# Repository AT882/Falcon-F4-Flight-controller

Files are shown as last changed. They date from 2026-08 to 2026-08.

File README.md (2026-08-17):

# Falcon F4 Flight Controller

Custom STM32F405-based flight controller designed for UAV, FPV and aerial robotics applications.

## Overview

The Falcon F4 Flight Controller is a custom-designed flight-control board based on the STM32F405RGT6 ARM Cortex-M4 microcontroller.

The board integrates the core hardware required for a compact UAV flight-control system, including a 6-axis IMU, barometric pressure sensor, analog video OSD, external SPI Flash memory, regulated power supplies, battery-voltage monitoring, current sensing, ESC interfaces, camera and VTX interfaces, USB connectivity and SWD debugging.

The complete electrical schematic is provided in this repository along with images of the designed PCB.

## Hardware Images

### PCB Front View

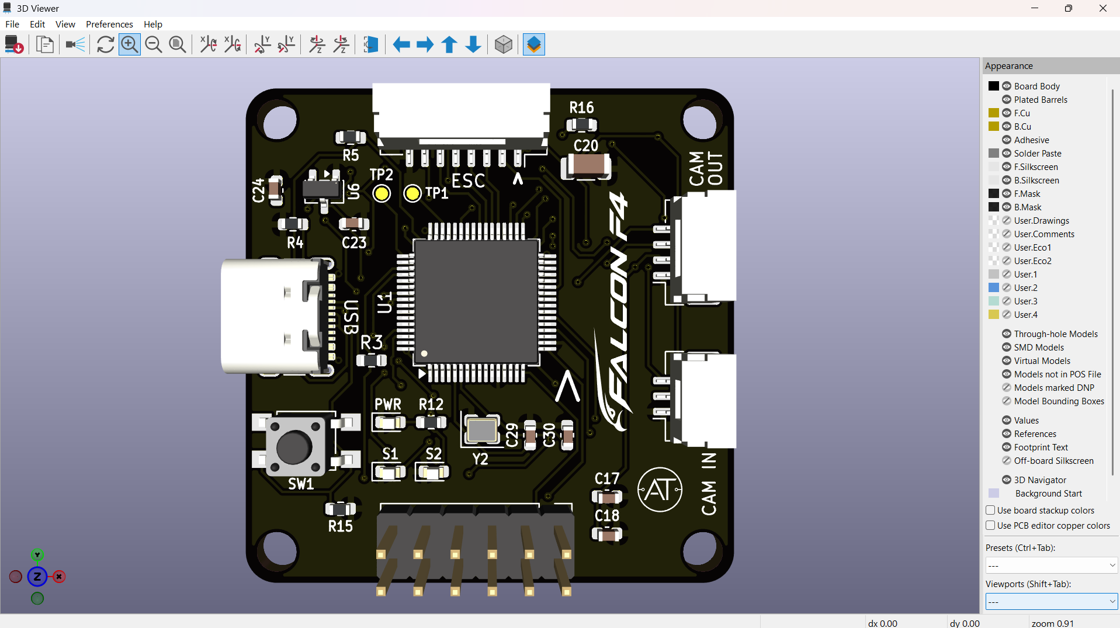
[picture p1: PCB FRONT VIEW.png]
Falcon F4 Flight Controller - Front View


### PCB Back View

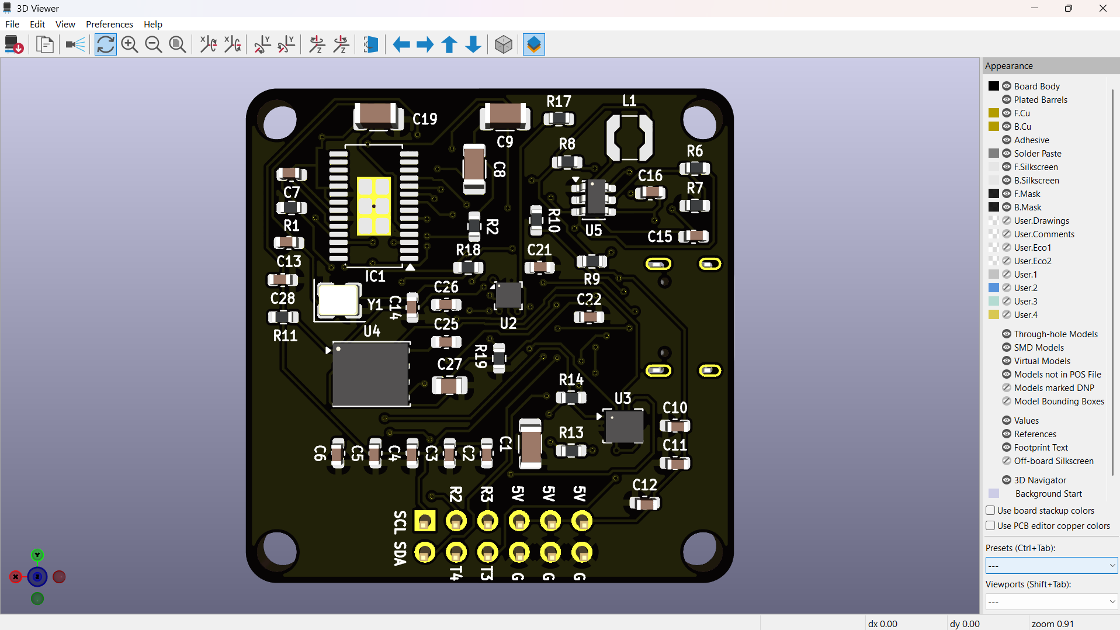
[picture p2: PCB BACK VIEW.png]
Falcon F4 Flight Controller - Back View

## Key Features

* STM32F405RGT6 ARM Cortex-M4 microcontroller
* ICM-42688-P 6-axis IMU
* BMP388 barometric pressure sensor
* AT7456E analog OSD controller
* W25Q128JV 128-Mbit SPI NOR Flash
* TPS54202DDCR 5 V buck regulator
* XC6206P332MR 3.3 V LDO regulator
* USB Type-C interface
* SWD programming and debugging interface
* Dedicated boot-mode selection
* Multiple ESC signal outputs
* ESC telemetry interface
* Analog camera input
* Analog VTX output
* Battery-voltage monitoring
* Current-sense input
* SPI interfaces
* I²C interface
* Status LEDs
* Power indication
* Dedicated MCU and OSD clock sources

## Main Processing Unit

### STM32F405RGT6

The STM32F405RGT6 is the main processing unit of the Falcon F4.

It provides the processing capability required for real-time flight-control applications and interfaces with the onboard sensors, memory, OSD circuitry, external peripherals and flight-control interfaces.

The MCU provides connections for:

* IMU
* Barometer
* SPI Flash
* OSD
* ESC interfaces
* Battery-voltage monitoring
* Current sensing
* I²C peripherals
* USB
* SWD
* Status LEDs
* Auxiliary GPIO

## Inertial Measurement Unit

### ICM-42688-P

The ICM-42688-P is used as the primary inertial measurement unit.

It provides:

* 3-axis accelerometer
* 3-axis gyroscope

The IMU is connected to the STM32 through an SPI interface.

The main IMU signals are:

```text
SPI1_SCK
SPI1_MISO
SPI1_MOSI
IMU_CS
```

The IMU has local decoupling capacitors to provide a stable supply and reduce supply noise.

The sensor provides motion information required for:

* Attitude estimation
* Angular-rate measurement
* Flight stabilization
* Orientation estimation
* Flight-control algorithms

## Barometric Pressure Sensor

### BMP388

The BMP388 is used for barometric pressure and altitude measurement.

The sensor is connected to the STM32 through the I²C interface.

The primary signals are:

```text
I2C1_SCL
I2C1_SDA
```

The barometer can be used for:

* Altitude estimation
* Altitude hold
* Vertical-position estimation
* Flight stabilization
* Autonomous UAV applications

## On-Screen Display

### AT7456E

The AT7456E is used as the analog video OSD controller.

The OSD section allows flight information to be overlaid onto the analog video stream.

The video path is:

```text
Camera
   |
   v
AV_IN
   |
   v
AT7456E
   |
   v
AV_OUT
   |
   v
VTX
```

The OSD section includes a dedicated 27 MHz crystal and associated circuitry.

Possible OSD information includes:

* Battery voltage
* Flight mode
* Altitude
* Flight status
* Warnings
* Navigation information
* Telemetry information
* Artificial horizon

## External Flash Memory

### W25Q128JV

The W25Q128JV is a 128-Mbit SPI NOR Flash memory device.

The external Flash provides non-volatile memory for storing application data.

Potential uses include:

* Configuration data
* Parameters
* Logging
* Flight data
* Application-specific information

The Flash interface uses:

```text
FLASH_CS
SPI3_SCK
SPI3_MISO
SPI3_MOSI
```

## Power Management

The Falcon F4 contains dedicated power-management circuitry for generating the required voltage rails.

The main power architecture consists of:

```text
+BATT
   |
   +------------------+
   |                  |
   v                  v
5 V Buck          Battery
Regulator         Monitoring
   |
   v
  5 V
   |
   v
3.3 V LDO
   |
   v
 3.3 V
```

## 5 V Regulator

### TPS54202DDCR

The TPS54202DDCR is used as the primary 5 V switching regulator.

The regulator converts the battery input into a regulated 5 V supply.

The regulator section includes:

* TPS54202DDCR
* Inductor
* Input capacitors
* Output capacitors
* Feedback network
* Enable circuitry
* Power flag

The 5 V rail supplies the OSD/video section and other peripherals requiring 5 V.

## 3.3 V Regulator

### XC6206P332MR

The XC6206P332MR provides the 3.3 V supply rail.

The 3.3 V rail powers the main low-voltage digital and sensor circuitry, including:

* STM32F405RGT6
* ICM-42688-P
* BMP388
* W25Q128JV
* Other 3.3 V peripherals

Local decoupling capacitors are provided for the regulator and individual ICs.

## Battery Voltage Monitoring

The Falcon F4 includes an onboard battery-voltage sensing circuit.

A resistor-divider network scales the battery voltage to a suitable level for the STM32 ADC.

The schematic uses:

```text
R18 = 20 kΩ
R19 = 1 kΩ
```

The scaled signal is connected to:

```text
ADC_IN8
```

This allows the flight-control firmware to monitor the connected battery voltage.

Battery-voltage monitoring can be used for:

* Battery status
* Low-voltage warnings
* Battery protection
* Flight telemetry
* Battery monitoring

## Current Monitoring

A dedicated current-sense input is provided.

The signal is labelled:

```text
CURRENT
```

and is connected to the STM32 ADC system.

The current measurement can be used for:

* Current monitoring
* Power-consumption estimation
* Battery monitoring
* Energy-consumption calculation
* Telemetry
* Low-battery management

The actual current-sensor implementation depends on the external ESC or power-monitoring hardware connected to the flight controller.

## ESC Interface

The Falcon F4 provides a dedicated multi-pin ESC interface.

The schematic includes:

```text
ESC_S1
ESC_S2
ESC_S3
ESC_S4
ESC_S5
ESC_S6
ESC_TLM
CURRENT
+BATT
GND
```

The interface is intended to connect the flight controller to external electronic speed controllers.

The multiple ESC signal connections allow the board to be adapted for different multirotor configurations.

The ESC interface can be used for:

* Motor-control signals
* ESC telemetry
* Current monitoring
* Battery monitoring

The exact communication protocol is determined by the flight-control firmware and connected ESC hardware.

## Camera Interface

A dedicated analog camera interface is provided.

The camera connector includes:

```text
GND
+5V
AV_IN
```

The camera video signal is routed to the AT7456E OSD section.

The OSD then overlays flight information onto the video stream before sending it to the VTX.

## VTX Interface

A dedicated VTX connector is provided.

The interface includes:

```text
GND
+BATT
AV_OUT
VTX_TBS
```

The processed analog video signal is available through:

```text
AV_OUT
```

The VTX control signal can be used with compatible video transmitters and firmware.

## USB Type-C Interface

The Falcon F4 includes a USB Type-C connector.

The USB section includes the required USB-C CC resistors and connections to the STM32.

The interface can be used for:

* Firmware development
* Configuration
* Data communication
* Firmware updates
* Development and testing

## Debugging and Programming

### SWD

A dedicated Serial Wire Debug interface is provided for programming and debugging the STM32F405.

The primary SWD signals are:

```text
SWDIO
SWCLK
```

The SWD interface can be used with an ST-LINK or compatible debugger.

It supports:

* Firmware programming
* Breakpoint debugging
* Register inspection
* Memory inspection
* Peripheral debugging
* Hardware bring-up

## Boot Mode

The board includes a dedicated boot-selection circuit.

The schematic provides:

```text
BOOT
BOOT0
```

along with a boot switch and associated pull-down circuitry.

This allows the MCU boot configuration to be selected during development and firmware recovery.

## Status LEDs

The Falcon F4 includes onboard status and power indication LEDs.

The schematic contains:

```text
LED1
LED2
POWER
```

These LEDs can be assigned by firmware to indicate:

* Power status
* Boot status
* Sensor initialization
* Flight-controller state
* Communication status
* Error conditions

## Clock Sources

The board contains dedicated clock sources for the MCU and OSD subsystem.

### MCU Clock

An 8 MHz crystal is provided for the STM32F405 clock system.

### OSD Clock

A separate 27 MHz crystal is provided for the AT7456E OSD controller.

## Communication Interfaces

### SPI

Multiple SPI interfaces are used for high-speed peripheral communication.

The SPI interfaces are used for devices including:

* ICM-42688-P
* W25Q128JV
* Other external peripherals

### I²C

The board provides an I²C interface for peripheral communication.

The primary signals are:

```text
I2C1_SCL
I2C1_SDA
```

The onboard BMP388 is connected through this interface.

## Major Components

| Reference | Component | Function |
| --- | --- | --- |
| U1 | STM32F405RGT6 | Main flight-controller MCU |
| U2 | BMP388 | Barometric pressure sensor |
| U3 | ICM-42688-P | 6-axis IMU |
| U4 | W25Q128JV | 128-Mbit SPI Flash |
| U5 | TPS54202DDCR | 5 V buck regulator |
| U6 | XC6206P332MR | 3.3 V LDO regulator |
| IC1 | AT7456E | Analog OSD controller |
| Y1 | 27 MHz crystal | OSD clock source |
| Y2 | 8 MHz crystal | MCU clock source |
| J1 | USB Type-C | USB interface |
| J2 | ESC connector | ESC interface |
| J3 | VTX connector | VTX interface |
| J4 | Camera connector | Camera interface |
| J5 | Auxiliary connector | External peripheral interface |
| SW1 | Boot switch | MCU boot selection |

## Intended Applications

The Falcon F4 is intended as a hardware platform for:

* FPV drones
* Multirotor UAVs
* Research UAVs
* Autonomous aerial vehicles
* Flight-control development
* UAV research
* Embedded systems development
* UAV education
* Custom flight-control firmware
* Robotics applications
* Experimental aircraft

## Schematic

The complete electrical schematic is provided in this repository.

The schematic contains the major functional sections of the flight controller:

* USB interface
* Battery input
* 5 V power regulation
* 3.3 V regulation
* STM32F405RGT6 MCU
* ICM-42688-P IMU
* BMP388 barometer
* AT7456E OSD
* W25Q128JV Flash
* ESC interface
* Camera interface
* VTX interface
* Battery-voltage sensing
* Current sensing
* SWD interface
* Boot circuit
* Status LEDs
* SPI interfaces
* I²C interface

## Repository Structure

```text
Falcon-F4-Flight-controller/
│
├── README.md
│
├── Schematic/
│   └── Falcon F4 Flightcontroller.kicad_sch
│
└── Images/
    ├── PCB FRONT VIEW.png
    └── PCB BACK VIEW.png
```

## Development Status

Current project status:

**Hardware schematic completed.**

The PCB design has been developed as a custom flight-controller platform based on the STM32F405RGT6.

The repository currently contains the electrical schematic and PCB documentation images.

Further development may include PCB manufacturing files, bill of materials, assembly documentation and firmware.

## Development and Testing

Recommended hardware bring-up sequence:

```text
Schematic Verification
        |
        v
PCB Fabrication
        |
        v
PCB Assembly
        |
        v
Visual Inspection
        |
        v
Power-Rail Verification
        |
        v
STM32 Programming
        |
        v
USB Verification
        |
        v
IMU Verification
        |
        v
Barometer Verification
        |
        v
Flash Verification
        |
        v
OSD and Video Verification
        |
        v
ESC Interface Verification
        |
        v
Flight-Control Firmware
        |
        v
UAV Integration
```

Initial testing should verify:

* Battery input
* 5 V rail
* 3.3 V rail
* MCU operation
* MCU reset
* MCU clock
* USB communication
* SWD communication
* IMU communication
* Barometer communication
* Flash communication
* Battery-voltage ADC measurement
* Current measurement
* ESC outputs
* OSD video input and output

## Safety and Testing Notice

This is a custom flight-controller hardware project.

The hardware should be thoroughly tested before installation on a flight-capable UAV.

Initial testing should be performed without propellers and with appropriate current limiting and laboratory power equipment.

Particular attention should be given to:

* Battery polarity
* Power-rail voltage
* Regulator temperature
* MCU temperature
* Sensor communication
* ADC voltage scaling
* ESC outputs
* Video signal integrity
* Connector polarity
* Short circuits
* PCB assembly quality

## Design Philosophy

The Falcon F4 was designed around four primary objectives.

### Performance

The STM32F405RGT6 provides a capable real-time processing platform suitable for UAV flight-control applications.

### Integration

The board integrates inertial sensing, barometric sensing, OSD, external Flash memory and power regulation into a single custom flight-controller platform.

### Expandability

SPI, I²C, ADC, GPIO and dedicated external connectors provide flexibility for additional sensors, ESCs, cameras, VTX systems and peripherals.

### Development

USB, SWD and BOOT interfaces simplify firmware development, debugging and hardware testing.

## Project Information

| Parameter | Details |
| --- | --- |
| Project Name | Falcon F4 Flight Controller |
| MCU | STM32F405RGT6 |
| IMU | ICM-42688-P |
| Barometer | BMP388 |
| OSD | AT7456E |
| External Flash  | W25Q128JV |
| 5 V Regulator | TPS54202DDCR |
| 3.3 V Regulator | XC6206P332MR |
| PCB Design Tool | KiCad |
| Application | UAV / FPV / Flight Control  |

## License

The licensing terms for the hardware design files and associated documentation will be specified as the project develops.

## Project

Falcon F4 Flight Controller

Custom STM32F405-based flight-control hardware platform for UAV, FPV and aerial robotics applications.

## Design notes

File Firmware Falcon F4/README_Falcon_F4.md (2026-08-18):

# Falcon F4 Flight Controller Firmware

The [Betaflight](https://github.com/betaflight/betaflight) firmware was used and tested for the Falcon F4 flight controller. The compiled `betaflight_4.5.2_Falcon_F4.hex` file can be used to flash the firmware. The configuration files are also available in the repository in case you want to compile the firmware yourself.

## How to Flash

The easiest way of flashing the firmware is using STM32CubeProgrammer. Other methods also exist, e.g. using [ST-LINK Utility](https://github.com/stlink-org/stlink) or [OpenOCD](https://github.com/openocd-org/openocd).

### Step 1

Install [STM32CubeProgrammer](https://www.st.com/en/development-tools/stm32cubeprog.html).

### Step 2

While holding the **BOOT/DFU button** on the Falcon F4 flight controller, plug in the USB-C cable and connect the flight controller to the computer. Release the button after connecting.

This puts the STM32 microcontroller into **DFU mode** and allows the firmware to be flashed over USB.

### Step 3

Open STM32CubeProgrammer. From the connection dropdown, select **USB**. A DFU device should appear in the **Port** section.

If the device does not appear, disconnect the USB cable and repeat **Step 2**.

<div style="text-align:center;">
STM32CubeProgrammer DFU
</div>

Click **Connect**.

### Step 4

Go to the **Erasing & Programming** tab and click **Full chip erase**.

<div style="text-align:center;">
STM32CubeProgrammer Programming tab
</div>

After the chip erase is complete, select the following firmware file included in the repository:

`betaflight_4.5.2_Falcon_F4.hex`

Click **Start Programming** and wait until the firmware has been completely flashed.

### Done

After programming is complete, disconnect and reconnect the USB cable.

The Falcon F4 flight controller should now boot with the flashed Betaflight firmware. You should be able to connect to it using the [Betaflight App](https://github.com/betaflight/betaflight-configurator).

<div style="text-align:center;">
Betaflight Configurator
</div>

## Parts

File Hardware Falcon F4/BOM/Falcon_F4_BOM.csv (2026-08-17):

Reference | Qty | Value | Footprint | Datasheet
C1 | 1 | 10uF | Capacitor_SMD:C_1206_3216Metric
C2,C3,C4,C5,C6,C7,C10,C11,C12,C15,C18,C21,C22,C25,C28 | 15 | 100nF | Capacitor_SMD:C_0603_1608Metric
C8,C9,C19,C20 | 4 | 22uF | Capacitor_SMD:C_1206_3216Metric
C13,C14,C29,C30 | 4 | 10pF | Capacitor_SMD:C_0603_1608Metric
C16 | 1 | 75pF | Capacitor_SMD:C_0603_1608Metric
C17 | 1 | 10uF | Capacitor_SMD:C_0603_1608Metric
C23,C24 | 2 | 1uF | Capacitor_SMD:C_0603_1608Metric
C26 | 1 | 10nF | Capacitor_SMD:C_0603_1608Metric
C27 | 1 | 2.2uF | Capacitor_SMD:C_0805_2012Metric
IC1 | 1 | AT7456E | Package_SO:TSSOP-28-1EP_4.4x9.7mm_P0.65mm_EP2.74x4.75mm | https://datasheet.lcsc.com/szlcsc/ZHONGKEWEI-AT7456E_C82351.pdf
J1 | 1 | USB_C_Receptacle_USB2.0_16P | Connector_USB:USB_C_Receptacle_GCT_USB4105-xx-A_16P_TopMnt_Horizontal | https://www.usb.org/sites/default/files/documents/usb_type-c.zip
J2 | 1 | ESC | Connector_JST:JST_GH_SM08B-GHS-TB_1x08-1MP_P1.25mm_Horizontal
J3 | 1 | VTX | Connector_JST:JST_GH_SM04B-GHS-TB_1x04-1MP_P1.25mm_Horizontal
J4 | 1 | CAM | Connector_JST:JST_GH_SM03B-GHS-TB_1x03-1MP_P1.25mm_Horizontal
J5 | 1 | CON | Connector_PinHeader_2.54mm:PinHeader_2x06_P2.54mm_Vertical
L1 | 1 | 15uH | Inductor_SMD:L_Coilcraft_LPS3314
PWR1 | 1 | POWER | LED_SMD:LED_0603_1608Metric
R1,R2 | 2 | 75R | Resistor_SMD:R_0603_1608Metric
R3,R4,R16,R17 | 4 | 5.1K | Resistor_SMD:R_0603_1608Metric
R5 | 1 | 1.5K | Resistor_SMD:R_0603_1608Metric
R6 | 1 | 511K | Resistor_SMD:R_0603_1608Metric
R7 | 1 | 105K | Resistor_SMD:R_0603_1608Metric
R8 | 1 | 49.9R | Resistor_SMD:R_0603_1608Metric
R9 | 1 | 100K | Resistor_SMD:R_0603_1608Metric
R10 | 1 | 13.3K | Resistor_SMD:R_0603_1608Metric
R11,R15 | 2 | 10K | Resistor_SMD:R_0603_1608Metric
R12,R13,R14,R19 | 4 | 1K | Resistor_SMD:R_0603_1608Metric
R18 | 1 | 20K | Resistor_SMD:R_0603_1608Metric
S1 | 1 | S1 | LED_SMD:LED_0603_1608Metric
S2 | 1 | S2 | LED_SMD:LED_0603_1608Metric
SW1 | 1 | BOOT | Button_Switch_SMD:SW_SPST_TL3305A
TP1 | 1 | SWDIO | TestPoint:TestPoint_Pad_D1.0mm
TP2 | 1 | SWCLK | TestPoint:TestPoint_Pad_D1.0mm
U1 | 1 | STM32F405RGTx | Package_QFP:LQFP-64_10x10mm_P0.5mm | https://www.st.com/resource/en/datasheet/stm32f405rg.pdf
U2 | 1 | BMP388 | Package_LGA:ST_HLGA-10_2x2mm_P0.5mm_LayoutBorder3x2y
U3 | 1 | ICM-42688-V | Package_LGA:LGA-14_3x2.5mm_P0.5mm_LayoutBorder3x4y
U4 | 1 | W25Q128JVP | Package_SON:WSON-8-1EP_6x5mm_P1.27mm_EP3.4x4.3mm | https://www.winbond.com/resource-files/w25q128jv_dtr%20revc%2003272018%20plus.pdf
U5 | 1 | TPS54202DDC | Package_TO_SOT_SMD:SOT-23-6 | http://www.ti.com/lit/ds/symlink/tps54202.pdf
U6 | 1 | XC6206PxxxMR | Package_TO_SOT_SMD:SOT-23-3 | https://www.torexsemi.com/file/xc6206/XC6206.pdf
Y1 | 1 | 27Mhz | Crystal:Crystal_SMD_3225-4Pin_3.2x2.5mm
Y2 | 1 | 8Mhz | Crystal:Crystal_SMD_2520-4Pin_2.5x2.0mm

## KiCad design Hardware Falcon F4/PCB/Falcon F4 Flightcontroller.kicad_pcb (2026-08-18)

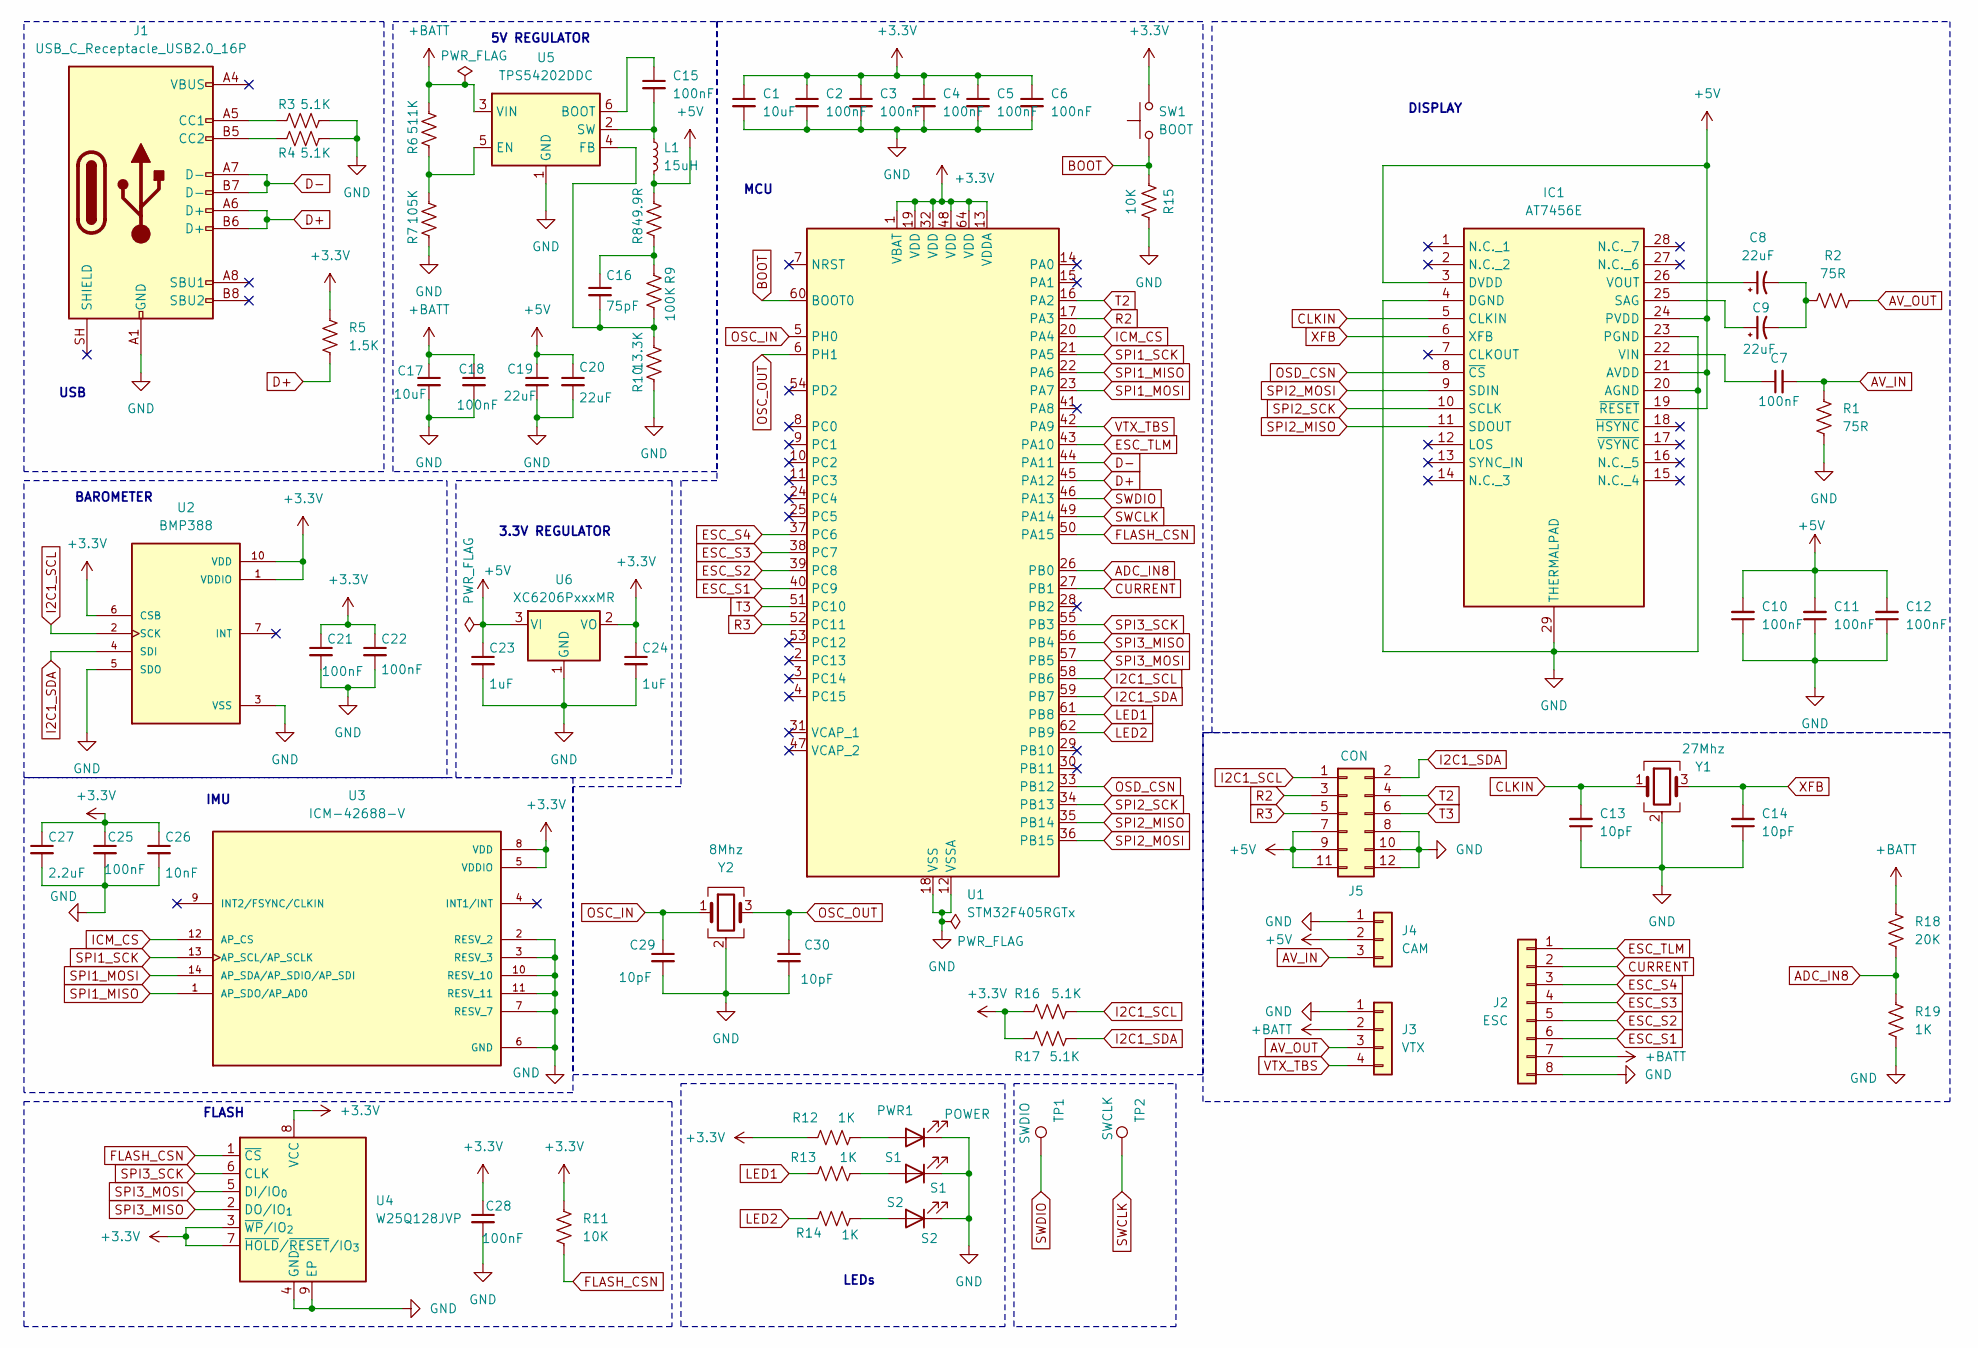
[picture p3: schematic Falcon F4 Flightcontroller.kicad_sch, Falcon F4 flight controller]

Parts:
C1: 10uF; C_1206_3216Metric
C2, C3, C4, C5, C6, C7, C10, C11, C12, C15, C18, C21, C22, C25, C28: 100nF; C_0603_1608Metric
C8, C9, C19, C20: 22uF; C_1206_3216Metric
C13, C14, C29, C30: 10pF; C_0603_1608Metric
C16: 75pF; C_0603_1608Metric
C17: 10uF; C_0603_1608Metric
C23, C24: 1uF; C_0603_1608Metric
C26: 10nF; C_0603_1608Metric
C27: 2.2uF; C_0805_2012Metric
IC1: AT7456E; TSSOP-28-1EP_4.4x9.7mm_P0.65mm_EP2.74x4.75mm; Manufacturer_Part_Number AT7456E
J1: USB_C_Receptacle_USB2.0_16P; USB_C_Receptacle_GCT_USB4105-xx-A_16P_TopMnt_Horizontal
J2: ESC; JST_GH_SM08B-GHS-TB_1x08-1MP_P1.25mm_Horizontal
J3: VTX; JST_GH_SM04B-GHS-TB_1x04-1MP_P1.25mm_Horizontal
J4: CAM; JST_GH_SM03B-GHS-TB_1x03-1MP_P1.25mm_Horizontal
J5: CON; PinHeader_2x06_P2.54mm_Vertical
L1: 15uH; L_Coilcraft_LPS3314
PWR1: POWER; LED_0603_1608Metric
R1, R2: 75R; R_0603_1608Metric
R3, R4, R16, R17: 5.1K; R_0603_1608Metric
R5: 1.5K; R_0603_1608Metric
R6: 511K; R_0603_1608Metric
R7: 105K; R_0603_1608Metric
R8: 49.9R; R_0603_1608Metric
R9: 100K; R_0603_1608Metric
R10: 13.3K; R_0603_1608Metric
R11, R15: 10K; R_0603_1608Metric
R12, R13, R14, R19: 1K; R_0603_1608Metric
R18: 20K; R_0603_1608Metric
S1: S1; LED_0603_1608Metric
S2: S2; LED_0603_1608Metric
SW1: BOOT; SW_SPST_TL3305A
TP1: SWDIO; TestPoint_Pad_D1.0mm
TP2: SWCLK; TestPoint_Pad_D1.0mm
U1: STM32F405RGTx; LQFP-64_10x10mm_P0.5mm
U2: BMP388; ST_HLGA-10_2x2mm_P0.5mm_LayoutBorder3x2y; PARTREV 1.7
U3: ICM-42688-V; LGA-14_3x2.5mm_P0.5mm_LayoutBorder3x4y
U4: W25Q128JVP; WSON-8-1EP_6x5mm_P1.27mm_EP3.4x4.3mm
U5: TPS54202DDC; SOT-23-6
U6: XC6206PxxxMR; SOT-23-3
Y1: 27Mhz; Crystal_SMD_3225-4Pin_3.2x2.5mm
Y2: 8Mhz; Crystal_SMD_2520-4Pin_2.5x2.0mm

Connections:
+3.3V: C1.1, C2.1, C3.1, C4.1, C5.1, C6.1, C21.1, C22.1, C24.1, C25.1, C26.1, C27.1, C28.1, R5.2, R11.2, R12.2, R16.2, R17.2, SW1.2, U1.1 (VBAT), U1.13 (VDDA), U1.19 (VDD), U1.32 (VDD), U1.48 (VDD), U1.64 (VDD), U2.1 (VDDIO), U2.6 (CSB), U2.10 (VDD), U3.5 (VDDIO), U3.8 (VDD), U4.3 (~WP/IO_{2}), U4.7 (~HOLD/~RESET/IO_{3}), U4.8 (VCC), U6.2 (VO)
+5V: C10.2, C11.2, C12.2, C19.1, C20.1, C23.1, IC1.3 (DVDD), IC1.19 (~RESET), IC1.21 (AVDD), IC1.24 (PVDD), J4.2, J5.7, J5.9, J5.11, L1.2, R8.2, U6.3 (VI); also elsewhere on the board
+BATT: C17.1, C18.1, J2.7, J3.2, R6.2, R18.1, U5.3 (VIN); also elsewhere on the board
ADC_IN8: R18.2, R19.1, U1.26 (PB0)
AV_IN: C7.2, J4.3, R1.1; also elsewhere on the board
AV_OUT: J3.3, R2.2; also elsewhere on the board
BOOT: R15.2, SW1.1, U1.60 (BOOT0)
CLKIN: C13.2, IC1.5 (CLKIN), Y1.1
CURRENT: J2.2, U1.27 (PB1); also elsewhere on the board
D+: J1.A6 (D+), J1.B6 (D+), R5.1, U1.45 (PA12); also elsewhere on the board
D-: J1.A7 (D-), J1.B7 (D-), U1.44 (PA11); also elsewhere on the board
ESC_S1: J2.6, U1.40 (PC9); also elsewhere on the board
ESC_S2: J2.5, U1.39 (PC8); also elsewhere on the board
ESC_S3: J2.4, U1.38 (PC7); also elsewhere on the board
ESC_S4: J2.3, U1.37 (PC6); also elsewhere on the board
ESC_TLM: J2.1, U1.43 (PA10); also elsewhere on the board
FLASH_CSN: R11.1, U1.50 (PA15), U4.1 (~CS)
GND: C1.2, C2.2, C3.2, C4.2, C5.2, C6.2, C10.1, C11.1, C12.1, C13.1, C14.1, C17.2, C18.2, C19.2, C20.2, C21.2, C22.2, C23.2, C24.2, C25.2, C26.2, C27.2, C28.2, C29.2, C30.2, IC1.4 (DGND), IC1.20 (AGND), IC1.23 (PGND), IC1.29 (THERMALPAD), J1.A1 (GND), J1.A12 (GND), J1.B1 (GND), J1.B12 (GND), J2.8, J3.1, J4.1, J5.8, J5.10, J5.12, PWR1.1 (K), R1.2, R3.2, R4.2, R7.1, R10.1, R15.1, R19.2, S1.1 (K), S2.1 (K), U1.12 (VSSA), U1.18 (VSS), U1.63 (VSS), U2.3 (VSS), U2.5 (SDO), U2.8 (VSS), U2.9 (VSS), U3.2 (RESV_2), U3.3 (RESV_3), U3.6 (GND), U3.7 (RESV_7), U3.10 (RESV_10), U3.11 (RESV_11), U4.4 (GND), U4.9 (EP), U5.1 (GND), U6.1 (GND), Y1.2 (G), Y1.4 (G), Y2.2 (G), Y2.4 (G); also elsewhere on the board
I2C1_SCL: J5.1, R16.1, U1.58 (PB6), U2.2 (SCK)
I2C1_SDA: J5.2, R17.1, U1.59 (PB7), U2.4 (SDI)
ICM_CS: U1.20 (PA4), U3.12 (AP_CS)
LED1: R13.2, U1.61 (PB8)
LED2: R14.2, U1.62 (PB9)
unnamed: C8.2, C9.2, R2.1
unnamed: C16.1, R8.1, R9.1
unnamed: C9.1, IC1.25 (SAG)
unnamed: C7.1, IC1.22 (VIN)
unnamed: C8.1, IC1.26 (VOUT)
unnamed 28: J1.A5 (CC1), R3.1; also elsewhere on the board
unnamed 29: J1.B5 (CC2), R4.1; also elsewhere on the board
unnamed: J1.A4 (VBUS), J1.A9 (VBUS), J1.B4 (VBUS), J1.B9 (VBUS)
unnamed 31: PWR1.2 (A), R12.1; also elsewhere on the board
unnamed: R13.1, S1.2 (A)
unnamed: R14.1, S2.2 (A)
unnamed: C15.1, U5.6 (BOOT)
unnamed: R6.1, R7.2, U5.5 (EN)
unnamed: C16.2, R9.2, R10.2, U5.4 (FB)
unnamed: C15.2, L1.1, U5.2 (SW)
OSC_IN: C29.1, U1.5 (PH0), Y2.1
OSC_OUT: C30.1, U1.6 (PH1), Y2.3
OSD_CSN: IC1.8 (~CS), U1.33 (PB12)
R2: J5.3, U1.17 (PA3)
R3: J5.5, U1.52 (PC11)
SPI1_MISO: U1.22 (PA6), U3.1 (AP_SDO/AP_AD0)
SPI1_MOSI: U1.23 (PA7), U3.14 (AP_SDA/AP_SDIO/AP_SDI)
SPI1_SCK: U1.21 (PA5), U3.13 (AP_SCL/AP_SCLK)
SPI2_MISO: IC1.11 (SDOUT), U1.35 (PB14)
SPI2_MOSI: IC1.9 (SDIN), U1.36 (PB15)
SPI2_SCK: IC1.10 (SCLK), U1.34 (PB13)
SPI3_MISO: U1.56 (PB4), U4.2 (DO/IO_{1})
SPI3_MOSI: U1.57 (PB5), U4.5 (DI/IO_{0})
SPI3_SCK: U1.55 (PB3), U4.6 (CLK)
SWCLK: TP2.1 (1_1), U1.49 (PA14)
SWDIO: TP1.1 (1_1), U1.46 (PA13)
T2: J5.4, U1.16 (PA2)
T3: J5.6, U1.51 (PC10)
VTX_TBS: J3.4, U1.42 (PA9); also elsewhere on the board
XFB: C14.2, IC1.6 (XFB), Y1.3

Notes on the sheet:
3.3V REGULATOR
IMU
MCU
LEDs
USB
BAROMETER
FLASH
5V REGULATOR
DISPLAY

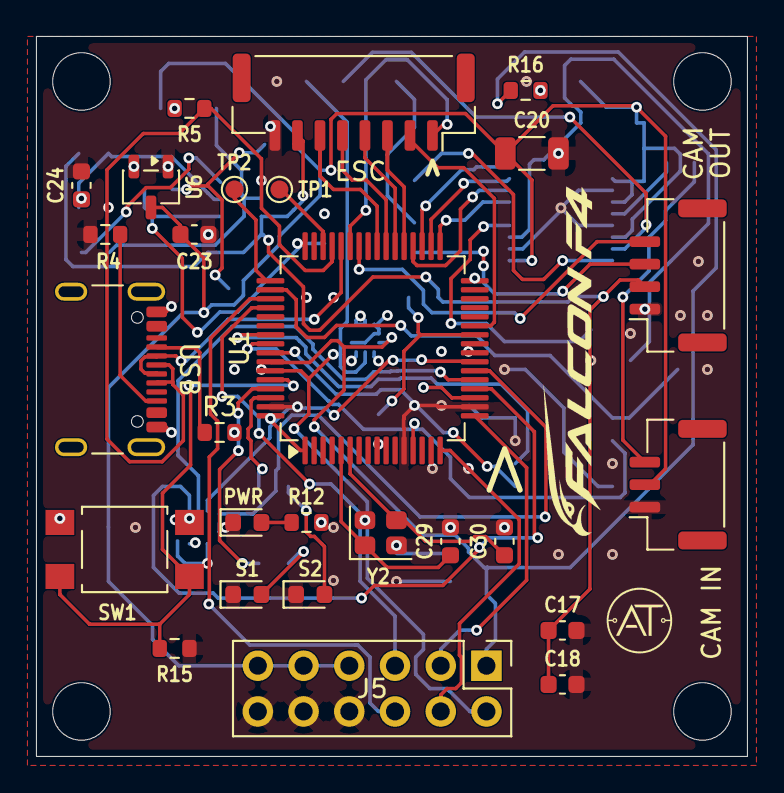
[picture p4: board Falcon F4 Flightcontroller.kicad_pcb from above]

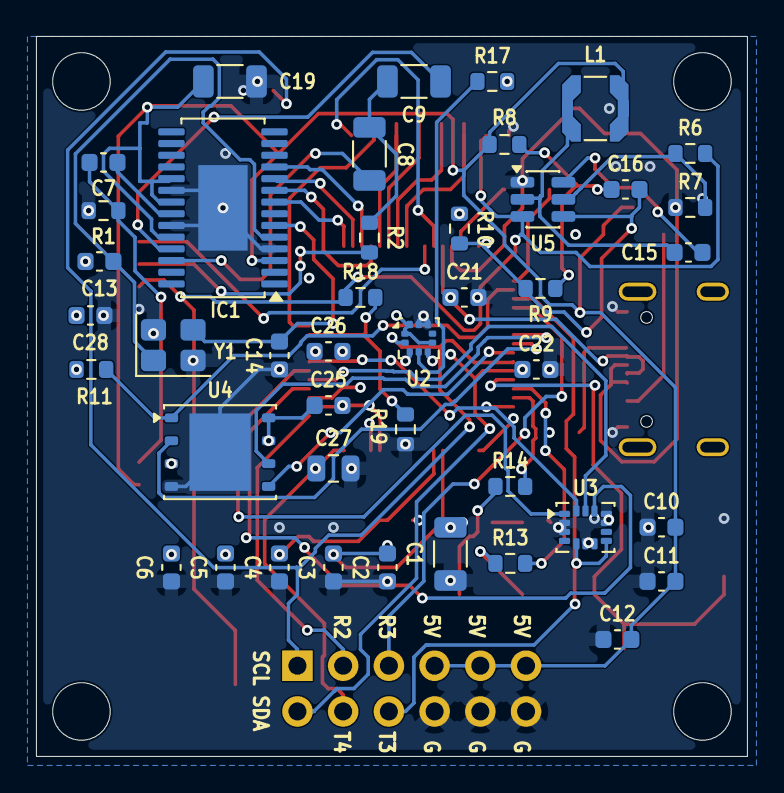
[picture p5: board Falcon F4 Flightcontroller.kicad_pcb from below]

Board: 4 copper layers, 39.5 x 40.0 mm, 74 parts (43 on the bottom side), 57 nets.

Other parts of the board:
CAM: VTX; JST_GH_SM04B-GHS-TB_1x04-1MP_P1.25mm_Horizontal
CAM IN: CAM; JST_GH_SM03B-GHS-TB_1x03-1MP_P1.25mm_Horizontal
ESC: ESC; JST_GH_SM08B-GHS-TB_1x08-1MP_P1.25mm_Horizontal
H1, H2, H3, H4: MountingHole_3.2mm_M3
PWR: POWER; LED_0603_1608Metric
USB: USB_C_Receptacle_USB2.0_16P; USB_C_Receptacle_GCT_USB4105-xx-A_16P_TopMnt_Horizontal

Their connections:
+5V: CAM IN.2; also elsewhere on the board
+BATT: CAM.2, ESC.7; also elsewhere on the board
AV_IN: CAM IN.3; also elsewhere on the board
AV_OUT: CAM.3; also elsewhere on the board
CURRENT: ESC.2; also elsewhere on the board
D+: USB.A6 (D+), USB.B6 (D+); also elsewhere on the board
D-: USB.A7 (D-), USB.B7 (D-); also elsewhere on the board
ESC_S1: ESC.6; also elsewhere on the board
ESC_S2: ESC.5; also elsewhere on the board
ESC_S3: ESC.4; also elsewhere on the board
ESC_S4: ESC.3; also elsewhere on the board
ESC_TLM: ESC.1; also elsewhere on the board
GND: CAM.1, CAM IN.1, ESC.8, PWR.1 (K), USB.A1 (GND), USB.A12 (GND), USB.B1 (GND), USB.B12 (GND); also elsewhere on the board
unnamed 28: USB.A5 (CC1); also elsewhere on the board
unnamed 29: USB.B5 (CC2); also elsewhere on the board
unnamed 31: PWR.2 (A); also elsewhere on the board
VTX_TBS: CAM.4; also elsewhere on the board
